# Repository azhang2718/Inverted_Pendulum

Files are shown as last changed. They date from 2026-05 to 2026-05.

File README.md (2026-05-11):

# Inverted Pendulum Control System

This page showcases an inverted pendulum on a cart, stabilized in real time by a custom PCB running a PID controller on a TI MSPM0G3507 as part of our final project for **ELEC 327 — Junior Design Lab**.

**Team:** Anthony Zhang · Bilin Yang · Brandon Sung · Setsuna Jiang

---

## Overview

The inverted pendulum is a classic control-theory benchmark: a rigid rod pivots freely on top of a cart that slides along a linear rail, and the controller must drive the cart left and right fast enough to keep the rod balanced upright. The upright position is inherently unstable, so any small tilt has to be detected and corrected before gravity wins.

Our implementation reads the pendulum angle from an AS5600 magnetic encoder over I²C, runs a PID loop at 200 Hz on a custom PCB, and drives a NEMA 17 stepper through a DRV8825 to move the cart along a V-slot aluminum rail.

---

## Hardware

| Component | Part | Role |
|---|---|---|
| Microcontroller | TI MSPM0G3507 | Runs the 200 Hz PID loop |
| Angle sensor | AS5600 magnetic encoder (I²C) | Reads pendulum angle (12-bit) |
| Magnet | Diametrically magnetized, 6 mm OD | Required for AS5600 to detect rotation |
| Motor | NEMA 17 stepper | Drives the cart |
| Motor driver | DRV8825 | STEP/DIR interface, 1/8 microstepping |
| Rail | V-slot aluminum extrusion + GT2 belt | Cart travel |
| Cart | V-slot gantry plate + V-wheels | Rides the rail |
| Bearings | 625RS | Pulley + idler support |
| Endstops | Limit switches (×2) | Homing on startup |
| Power | 12 V / 5 A supply | Motor + logic rail |
| Regulator | LM1117 3.3 V LDO | Logic supply |
| Pendulum | 6 mm × 300 mm steel rod | The thing being balanced |

The full PCB design is in `pcb/` as a KiCad project. Open `*.kicad_pro` in the KiCad project manager to view the schematic and layout

---

## Software

### Control loop

A standard PID controller on the pendulum angle:

- **P** — proportional response to current tilt
- **I** — corrects for slow drift / sensor offset
- **D** — damps oscillation by reacting to angular velocity

The loop runs at 200 Hz. PID gains are stored as integers scaled by 100 so all arithmetic stays in fixed-point — no FPU needed, and the timing is deterministic.

### `config.h`

Every tunable value in the project lives in a single header. The idea is that PID tuning is iterative — you change a number, flash, test, repeat — and having every constant in one place makes that loop fast and error-free.

Things in `config.h`:
- `KP`, `KI`, `KD` — PID gains (scaled ×100)
- `MIN_STEP_RATE`, `MAX_STEP_RATE` — motor speed bounds (prevents stall and runaway)
- `DEADBAND` — angle window where no correction is applied
- `ENGAGE_THRESHOLD` — angle within which the controller activates
- `GIVE_UP_THRESHOLD` — angle past which the controller disengages
- `INTEGRAL_CLAMP` — anti-windup limit on the integral term
- `MOTOR_DIR_SIGN` — direction polarity

### I²C driver (AS5600)

The angle sensor is read over I²C from the raw-angle register. The driver:

1. Waits for the bus to be idle
2. Flushes the TX FIFO
3. Writes the target register address
4. Reads back two bytes → 12-bit angle

Every busy-wait loop has a **timeout counter** that decrements and returns an error code if it hits zero. Without these, a single bad I²C transaction could lock the entire control loop — and on a pendulum that's trying to balance, a hang means it falls instantly.

### Startup sequence

1. Init peripherals (I²C, timers, GPIO)
2. Home the cart against the limit switches and zero the step counter
3. Move cart to center of the rail
4. Wait until the pendulum is within `ENGAGE_THRESHOLD` of vertical
5. Enable PID loop

---

## Building & Flashing

1. Install **Code Composer Studio** (or use the TI Arm Clang toolchain directly).
2. Open the firmware project, build, and flash via the SWD header on the PCB.
3. Adjust values in `inc/config.h` as needed and reflash to tune.

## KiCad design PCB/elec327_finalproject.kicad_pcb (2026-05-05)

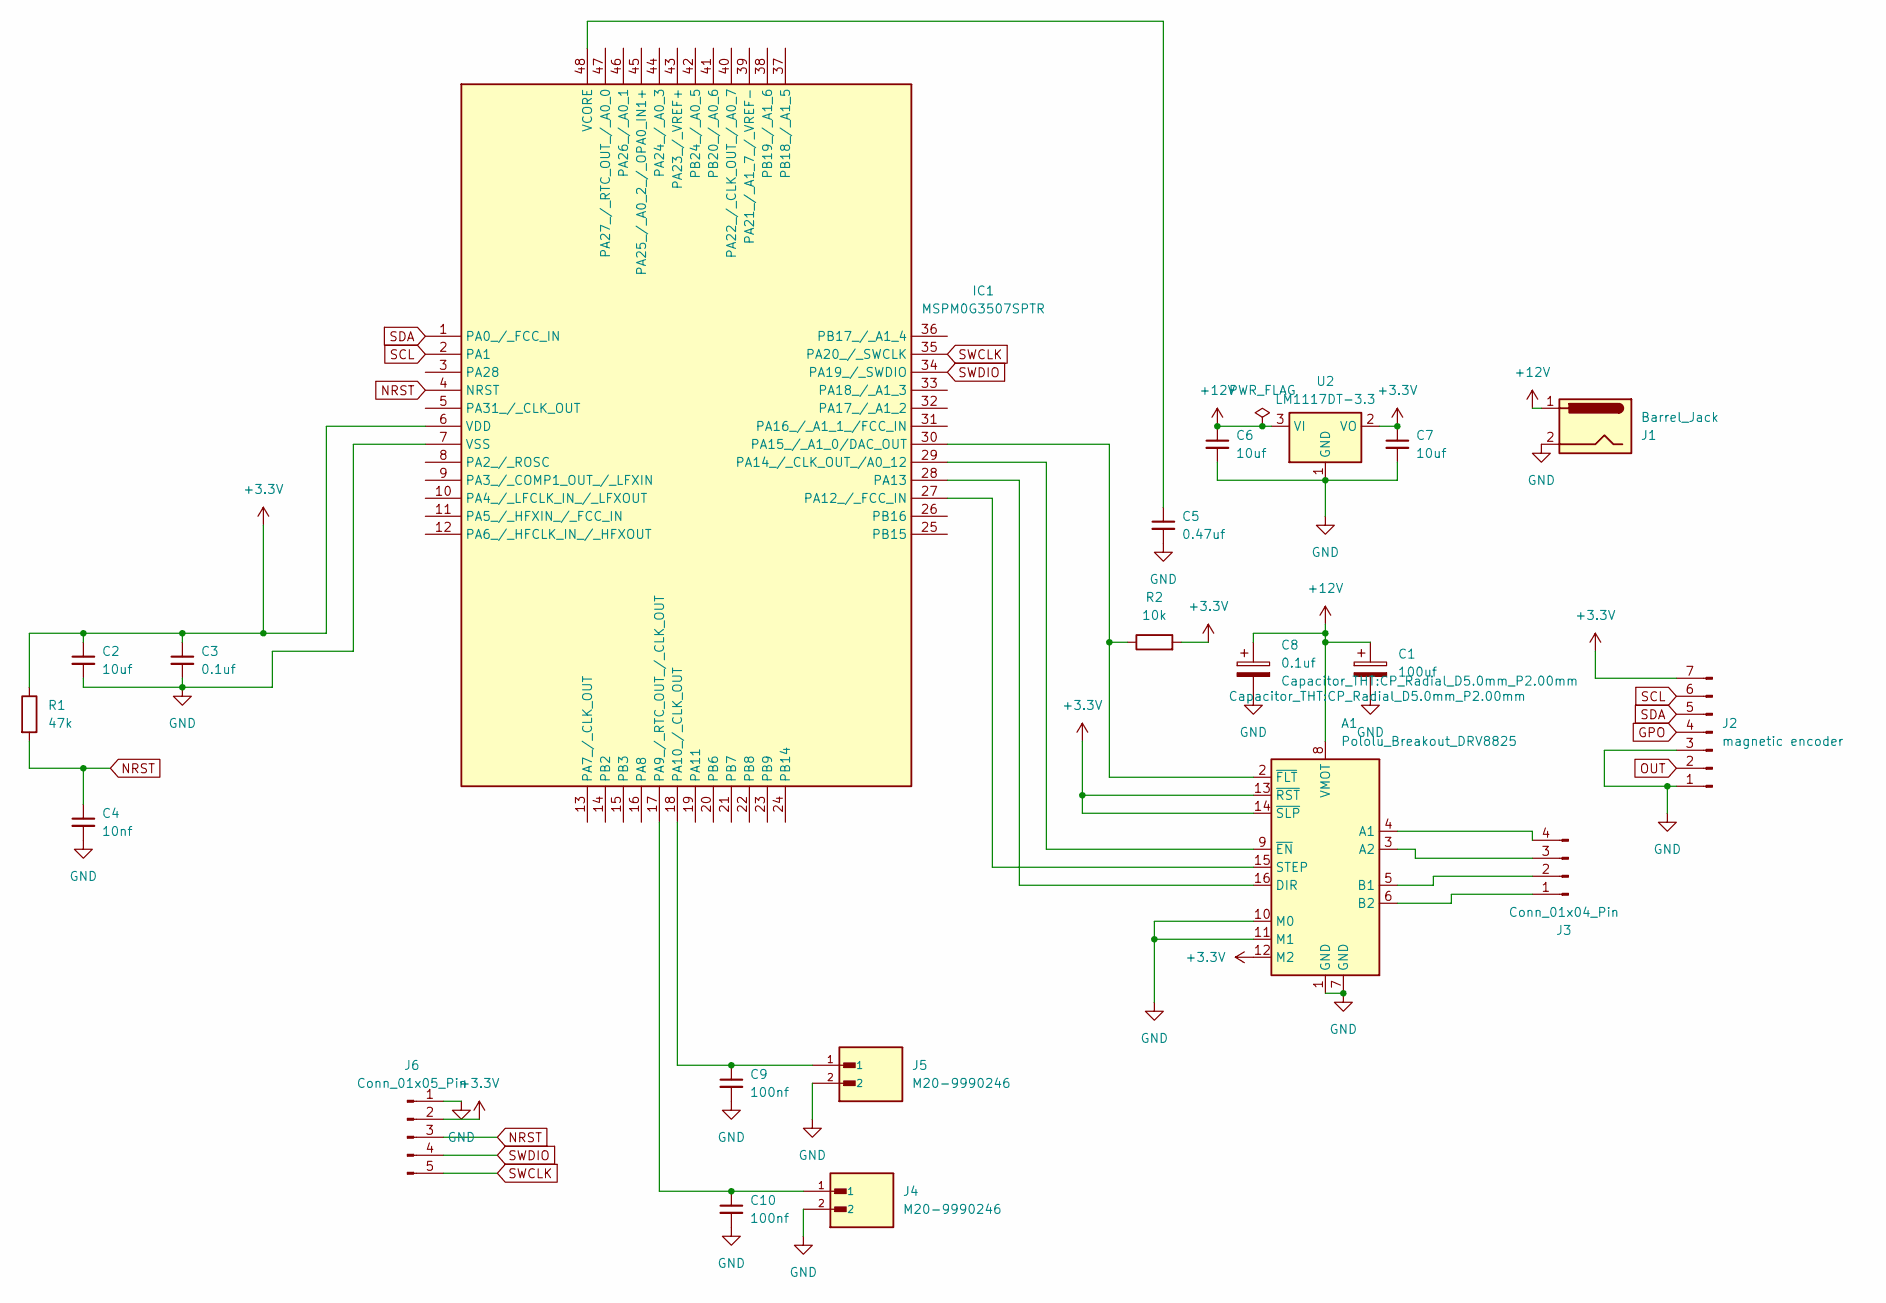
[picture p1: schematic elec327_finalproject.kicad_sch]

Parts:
A1: Pololu_Breakout_DRV8825; Pololu_Breakout-16_15.2x20.3mm
C1: 100uf; CP_Radial_D5.0mm_P2.00mm
C2, C6, C7: 10uf; C_0805_2012Metric_Pad1.18x1.45mm_HandSolder
C3: 0.1uf; C_0805_2012Metric_Pad1.18x1.45mm_HandSolder
C4: 10nf; C_0805_2012Metric_Pad1.18x1.45mm_HandSolder
C5: 0.47uf; C_0805_2012Metric_Pad1.18x1.45mm_HandSolder
C8: 0.1uf; CP_Radial_D5.0mm_P2.00mm
C9, C10: 100nf; C_0805_2012Metric_Pad1.18x1.45mm_HandSolder
IC1: MSPM0G3507SPTR; QFP50P900X900X160-48N; Mouser Part Number 595-MSPM0G3507SPTR
J1: Barrel_Jack; BarrelJack_SwitchcraftConxall_RAPC10U_Horizontal
J2: magnetic encoder; PinHeader_1x07_P2.54mm_Vertical
J3: Conn_01x04_Pin; PinHeader_1x04_P2.54mm_Vertical
J4, J5: M20-9990246; HARWIN_M20-9990246; PARTREV 14
J6: Conn_01x05_Pin; PinHeader_1x05_P2.54mm_Vertical
R1: 47k; R_0805_2012Metric_Pad1.20x1.40mm_HandSolder
R2: 10k; R_0805_2012Metric_Pad1.20x1.40mm_HandSolder
U2: LM1117DT-3.3; TO-252-3_TabPin2

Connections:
+3.3V: A1.12 (M2), A1.13 (~RST), A1.14 (~SLP), C2.1, C3.1, C7.1, IC1.6 (VDD), J2.7, J6.2, R1.1, R2.2, U2.2 (VO)
+12V: A1.8 (VMOT), C1.1, C6.1, C8.1, J1.1, U2.3 (VI)
GND: A1.1 (GND), A1.7 (GND), A1.10 (M0), A1.11 (M1), C1.2, C2.2, C3.2, C4.2, C5.2, C6.2, C7.2, C8.2, C9.2, C10.2, IC1.7 (VSS), J1.2, J2.1, J2.3, J4.2, J5.2, J6.1, U2.1 (GND)
GPO: J2.4
NRST: C4.1, IC1.4 (NRST), J6.3, R1.2
unnamed: A1.4 (A1), J3.4
unnamed: A1.3 (A2), J3.3
unnamed: A1.5 (B1), J3.2
unnamed: A1.6 (B2), J3.1
unnamed: A1.16 (DIR), IC1.28 (PA13)
unnamed: A1.15 (STEP), IC1.27 (PA12_/_FCC_IN)
unnamed: A1.9 (~EN), IC1.29 (PA14_/_CLK_OUT_/A0_12)
unnamed: A1.2 (~FLT), IC1.30 (PA15_/_A1_0/DAC_OUT), R2.1
unnamed: C10.1, IC1.17 (PA9_/_RTC_OUT_/_CLK_OUT), J4.1
unnamed: C9.1, IC1.18 (PA10_/_CLK_OUT), J5.1
unnamed: C5.1, IC1.48 (VCORE)
OUT: J2.2
SCL: IC1.2 (PA1), J2.6
SDA: IC1.1 (PA0_/_FCC_IN), J2.5
SWCLK: IC1.35 (PA20_/_SWCLK), J6.5
SWDIO: IC1.34 (PA19_/_SWDIO), J6.4

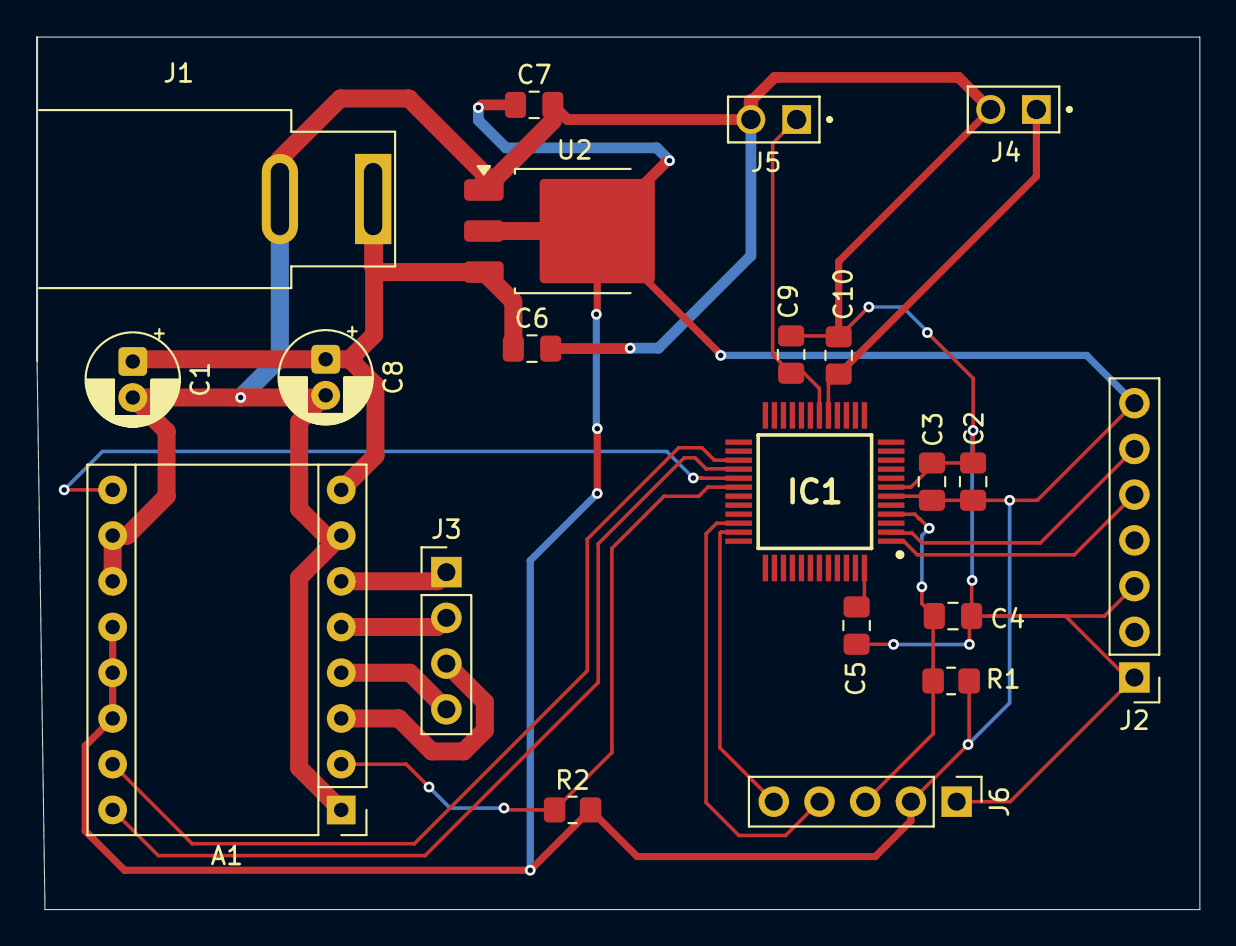
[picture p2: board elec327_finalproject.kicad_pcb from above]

Board: 2 copper layers, 64.6 x 48.5 mm, 21 parts (0 on the bottom side), 19 nets.

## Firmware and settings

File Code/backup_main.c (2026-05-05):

// #include "ti_msp_dl_config.h"
// #include <stdint.h>
// #include <stdbool.h>
// #include <math.h>

// // parameter

// // AS5600 I2C address and register
// #define AS5600_ADDR         0x36
// #define AS5600_RAW_ANGLE_H  0x0C

// // PWM period, 32MHz / 3200 = 10kHz step pulse)
// #define PWM_PERIOD          3200

// // Physical calibration
// #define STEPS_PER_MM        40.0      // how many steps does it take for the cart to move 1 millimeter, adjust later
// #define SCALE_FACTOR        (-1.0/100.0)  // scaling factor for the cart's position when calculating the PID input value
//                                           // negative sign indicates the direction
//                                           // Carey's non-inverted config
// #define OUTPUT_DIR          (-1)          // Motor rotation diretion, Carey's non-inverted config, adjust(1 or -1) later

// // PID gains (from Carey, tune after hardware test)
// #define KP  250.0
// #define KI    0.0
// #define KD    5.0

// // PID sample time in seconds, 5ms timer
// #define DT  0.005

// // Motor output limits, steps/s, maps to PWM duty cycle
// #define OUTPUT_MAX   5000.0
// #define OUTPUT_MIN  -5000.0

// // Pendulum considered fallen if |input| >= this threshold, then reset, adjust later
// #define FALL_THRESHOLD  150.0


// #define ANGLE_OFFSET_RAW  0  // measure and fill this later




// // Variables that need to be tracked during program

// // Global state
// // volatile: tell the compiler that this variable may be modified unexpectedly,
// // so it should not perform any optimizations and must re-read it from memory every time it's used
// volatile bool     g_timer_flag  = true; // start
// volatile uint16_t g_angle_raw   = 0;    // raw data read from AS5600, 0-4095
// volatile int32_t  g_step_count  = 0;   // cumulative steps, + -, for the position of cart


// double ang_deg; 

// // PID state
// // static: variable is only visible in the current file and remains in memory throughout programming
// static double g_integral   = 0.0; // the cumulative value of the integral term. 
//                                 // each time the control loop runs, the current error is multiplied by DT and added to this
//                                 // It records the accumulation of the error over time

// static double g_prev_error = 0.0; // the error value from the previous loop. 
//                                 // the derivative term is calculated by subtracting the previous error from the current error and dividing the result by DT
//                                 // estimate the rate of change of the error
//                                 // At the end of each loop, the current error is stored for use in the next loop

// uint16_t AS5600_ReadAngle(void)
// {
//     uint8_t reg = AS5600_RAW_ANGLE_H;

//     // ----- WRITE: send register address -----
//     // Wait for I2C to be idle before starting
//     while (!(DL_I2C_getControllerStatus(I2C_0_INST) &
//              DL_I2C_CONTROLLER_STATUS_IDLE));

//     DL_I2C_fillControllerTXFIFO(I2C_0_INST, &reg, 1);
//     DL_I2C_startControllerTransfer(I2C_0_INST, AS5600_ADDR,
//                                    DL_I2C_CONTROLLER_DIRECTION_TX, 1);

//     // Wait for transfer to finish
//     while (DL_I2C_getControllerStatus(I2C_0_INST) &
//            DL_I2C_CONTROLLER_STATUS_BUSY_BUS);

//     // Did the slave actually ACK?
//     if (DL_I2C_getControllerStatus(I2C_0_INST) &
//         DL_I2C_CONTROLLER_STATUS_ERROR) {
//         return 0xFFFF;  // sentinel for "comms failed"
//     }

//     // ----- READ: 2 bytes back -----
//     while (!(DL_I2C_getControllerStatus(I2C_0_INST) &
//              DL_I2C_CONTROLLER_STATUS_IDLE));

//     DL_I2C_startControllerTransfer(I2C_0_INST, AS5600_ADDR,
//                                    DL_I2C_CONTROLLER_DIRECTION_RX, 2);

//     // Wait for each byte to actually be in the RX FIFO before reading
//     while (DL_I2C_isControllerRXFIFOEmpty(I2C_0_INST));
//     uint8_t hi = DL_I2C_receiveControllerData(I2C_0_INST);

//     while (DL_I2C_isControllerRXFIFOEmpty(I2C_0_INST));
//     uint8_t lo = DL_I2C_receiveControllerData(I2C_0_INST);

//     // Wait for full transfer to complete and check error
//     while (DL_I2C_getControllerStatus(I2C_0_INST) &
//            DL_I2C_CONTROLLER_STATUS_BUSY_BUS);

//     if (DL_I2C_getControllerStatus(I2C_0_INST) &
//         DL_I2C_CONTROLLER_STATUS_ERROR) {
//         return 0xFFFF;
//     }

//     return ((uint16_t)(hi & 0x0F) << 8) | lo;
// }


// // // Read the current angle from the AS5600 via I2C, return a value between 0-4095
// // uint16_t AS5600_ReadAngle(void)
// // {
// //     uint8_t reg = AS5600_RAW_ANGLE_H; // address in temporary variable

// //     // I2C read
// //     DL_I2C_fillControllerTXFIFO(I2C_0_INST, &reg, 1); // put address in buffer
// //     DL_I2C_startControllerTransfer(I2C_0_INST, AS5600_ADDR,
// //         DL_I2C_CONTROLLER_DIRECTION_TX, 1); // TX: send
// //     while (DL_I2C_getControllerStatus(I2C_0_INST) &
// //            DL_I2C_CONTROLLER_STATUS_BUSY_BUS); // wait until send end

// //     // accept
// //     DL_I2C_startControllerTransfer(I2C_0_INST, AS5600_ADDR,
// //         DL_I2C_CONTROLLER_DIRECTION_RX, 2); // RX: accept
// //     while (DL_I2C_getControllerStatus(I2C_0_INST) &
// //            DL_I2C_CONTROLLER_STATUS_BUSY_BUS);

// //     // 12-digit angle number, 0-360
// //     uint8_t hi = DL_I2C_receiveControllerData(I2C_0_INST); // high byte
// //     uint8_t lo = DL_I2C_receiveControllerData(I2C_0_INST); // low byte
// //     return ((uint16_t)(hi & 0x0F) << 8) | lo; // add together
// // }



// // Motor
// // speed_signed: positive = forward, negative = backward
// // magnitude maps to PWM duty cycle
// void Motor_Set(double speed_signed)
// {
//     // control between -5000-5000
//     if (speed_signed > OUTPUT_MAX)  speed_signed =  OUTPUT_MAX;
//     if (speed_signed < OUTPUT_MIN)  speed_signed =  OUTPUT_MIN;


//     uint8_t dir;
//     double  spd;

//     if (speed_signed >= 0) {
//         dir = 1; // sign of speed
//         spd = speed_signed; // absolute value
//     } else {
//         dir = 0;
//         spd = -speed_signed;
//     }

//     int32_t steps_this_cycle = (int32_t)(spd * DT);

//     // Map speed (0~OUTPUT_MAX) to PWM compare value (0~PWM_PERIOD)
//     uint32_t compare = PWM_PERIOD - (uint32_t)(spd / OUTPUT_MAX * PWM_PERIOD); // explaination

//     if (dir) {
//         DL_GPIO_setPins(GPIO_GRP_0_PORT, GPIO_GRP_0_DIR_PIN);
//         g_step_count += steps_this_cycle; 
//     } else {
//         DL_GPIO_clearPins(GPIO_GRP_0_PORT, GPIO_GRP_0_DIR_PIN);
//         g_step_count -= steps_this_cycle; 
//     }
//     DL_TimerG_setCaptureCompareValue(PWM_0_INST, compare, DL_TIMER_CC_0_INDEX);
// }

// // stop
// void Motor_Stop(void)
// {
//     DL_TimerG_setCaptureCompareValue(PWM_0_INST, PWM_PERIOD, DL_TIMER_CC_0_INDEX);
// }

// // PID
// // double: 64-bit float
// double PID_Compute(double input)
// {
//     // setpoint is 0: we want input == 0
//     double error = 0.0 - input;

//     g_integral   += error * DT;

//     double deriv  = (error - g_prev_error) / DT;
//     g_prev_error  = error;
//     // If the object is tilting rapidly to one side, the differential component will detect this
//     // and apply a counterforce before the error becomes significant, prevent oscillation

//     return KP * error + KI * g_integral + KD * deriv; // Final output of PID
//     // KI=0 first
// }

// // Timer ISR (every 5ms), interrupt
// void TIMA0_IRQHandler(void)
// {
//     switch (DL_TimerA_getPendingInterrupt(TIMER_0_INST)) {
//         case DL_TIMERA_IIDX_ZERO:
//             g_timer_flag = true;
//             break;
//         default:
//             break;
//     }
// }

// // Main
// int main(void)
// {
//     SYSCFG_DL_init(); // start all
//     NVIC_EnableIRQ(TIMA0_INT_IRQn); // start check the interrrupt of TIMA0
//     DL_TimerA_startCounter(TIMER_0_INST);
//     DL_TimerG_startCounter(PWM_0_INST);

//     while (1) {
//         if (!g_timer_flag) continue;
//         g_timer_flag = true;
//         // prevent an interrupt being dealt twice

//         // 0-4095 -> angle -> degrees
//         g_angle_raw     = AS5600_ReadAngle();
//         int16_t corrected = (int16_t) g_angle_raw - ANGLE_OFFSET_RAW;
//         ang_deg  = corrected * (360.0 / 4096.0);
//         double ang_rad  = ang_deg * (3.14159265 / 180.0);

//         // Combine cart position and pendulum angle
//         // same as Carey's design
//         double cart_mm  = (double)g_step_count / STEPS_PER_MM;
//         double input    = SCALE_FACTOR * cart_mm + 200.0 * sin(ang_rad);

//         // Stop if pendulum has fallen
//         if (input > FALL_THRESHOLD || input < -FALL_THRESHOLD) {
//             Motor_Stop();
//             g_integral   = 0.0;
//             g_prev_error = 0.0;
//             continue;
//         }

//         // PID -> motor
//         double output = PID_Compute(input);
//         Motor_Set((double)OUTPUT_DIR * output);
//     }
// }

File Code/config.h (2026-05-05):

#ifndef CONFIG_H
#define CONFIG_H

#include <stdint.h>
#include <stdbool.h>

// === Hardware constants ===
#define AS5600_ADDR             0x36
#define AS5600_RAW_ANGLE_H      0x0C
#define COUNTS_PER_REV          4096
#define TIMER_CLK_HZ            1000000UL
#define TICK_MS                 5

// === Calibration ===
#define ANGLE_REFERENCE_COUNTS  44

// === Step rate window ===
#define MAX_STEP_HZ             2500U
#define MIN_STEP_HZ             400U
#define DEADBAND_COUNTS         5       

// === PID gains ===
#define KP_x100                 800
#define KI_x100                 0
#define KD_x100                 2000

// === Angle bands ===
#define ENGAGE_THRESHOLD_COUNTS 120
#define GIVE_UP_THRESHOLD_COUNTS 600
#define INTEGRAL_LIMIT          50000

// === Direction sign ===
#define MOTOR_DIRECTION_SIGN    (-1)


#endif

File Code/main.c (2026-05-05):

#include "ti_msp_dl_config.h"
#include "config.h"
#include "control.h"
#include "motor.h"
#include "state.h"
#include "angle_sensor.h"

// =====================================================================
// ISR SHARED FLAGS (must be here or externed)
// =====================================================================
static volatile bool g_tick = false;

// =====================================================================
// TIMER ISR
// =====================================================================
void TIMA0_IRQHandler(void)
{
    if (DL_TimerA_getPendingInterrupt(TIMER_0_INST) == DL_TIMERA_IIDX_ZERO) {
        g_tick = true;
    }
}

// =====================================================================
// GPIO ISR (LIMIT SWITCH HARD STOP)
// =====================================================================
void GROUP1_IRQHandler(void)
{
    uint32_t status = DL_GPIO_getEnabledInterruptStatus(
        LIMITS_PORT,
        LIMITS_LEFT_PIN | LIMITS_RIGHT_PIN
    );

    if (status & (LIMITS_LEFT_PIN | LIMITS_RIGHT_PIN)) {
        g_limit_tripped = true;   // global from control.c
        g_state = STATE_DISARMED;
        motor_stop();
    }

    DL_GPIO_clearInterruptStatus(LIMITS_PORT, status);
}

// =====================================================================
// MAIN LOOP
// =====================================================================
int main(void)
{
    SYSCFG_DL_init();

    NVIC_EnableIRQ(TIMA0_INT_IRQn);
    NVIC_EnableIRQ(GPIOA_INT_IRQn);

    DL_TimerA_startCounter(TIMER_0_INST);

    while (1) {
        if (!g_tick) {
            __WFI();
            continue;
        }

        g_tick = false;

        uint16_t angle;
        if (as5600_read_angle(&angle) == 0) {
            control_step(angle);          // computes g_error from angle
            update_state(g_error);        // <-- this is what's missing
            // then PID + motor_command based on g_state
        }

    }
}

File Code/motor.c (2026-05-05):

/*
* code for stepper motor driver
*/
#include "motor.h"
#include "ti_msp_dl_config.h"
#include "config.h"

//whether PWM for motor is running
static bool g_motor_on = false;

//direction control for motor
static void motor_dir_pos(void) { DL_GPIO_setPins(GPIO_GRP_0_PORT, GPIO_GRP_0_DIR_PIN); }
static void motor_dir_neg(void) { DL_GPIO_clearPins(GPIO_GRP_0_PORT, GPIO_GRP_0_DIR_PIN); }

//configure PWM for the requested frequency 
static void motor_run(uint32_t step_hz)
{
    //hard limit on smallest PWM
    if (step_hz < 10) step_hz = 10;
    uint32_t period = TIMER_CLK_HZ / step_hz;
    //hardware needs minimum count
    if (period < 4) period = 4;

    //use load val for period and compare val for duty cycle (50%)
    DL_TimerG_setLoadValue(PWM_0_INST, period - 1);
    DL_TimerG_setCaptureCompareValue(PWM_0_INST, period / 2, DL_TIMER_CC_0_INDEX);

    //only start counter if it isn't alr running
    if (!g_motor_on) {
        DL_TimerG_startCounter(PWM_0_INST);
        g_motor_on = true;
    }
}

// stop motor by stopping PWM
void motor_stop(void)
{
    if (g_motor_on) {
        //stop PWM
        DL_TimerG_stopCounter(PWM_0_INST);
        //set flag to false
        g_motor_on = false;
    }
}

//set direction and speed of motor
void motor_command(int8_t dir, uint32_t step_hz)
{
    if (dir != 0) {
        //set DIR pin before STEP to allow for setup time
        if (dir > 0) motor_dir_pos();
        else         motor_dir_neg();

        //wait a few us so DIR settles before next STEP
        for(volatile int i=0; i<100; i++);
        //alter motor PWM to change speed
        motor_run(step_hz);
    } else {
        motor_stop();
    }
}

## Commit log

2026-05-05 Add files via upload
    added PCB designs for controlling the inverted pendulum
    [elec327_finalproject.kicad_pcb, elec327_finalproject.kicad_sch]
2026-05-05 added PCB files
    [elec327_finalproject.kicad_pcb, elec327_finalproject.kicad_sch]
